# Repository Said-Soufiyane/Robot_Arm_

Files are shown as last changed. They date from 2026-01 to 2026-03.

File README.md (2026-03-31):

# Robot Arm (ESP32) — 6-Axis Desktop Arm (In Progress)

<p align="center">
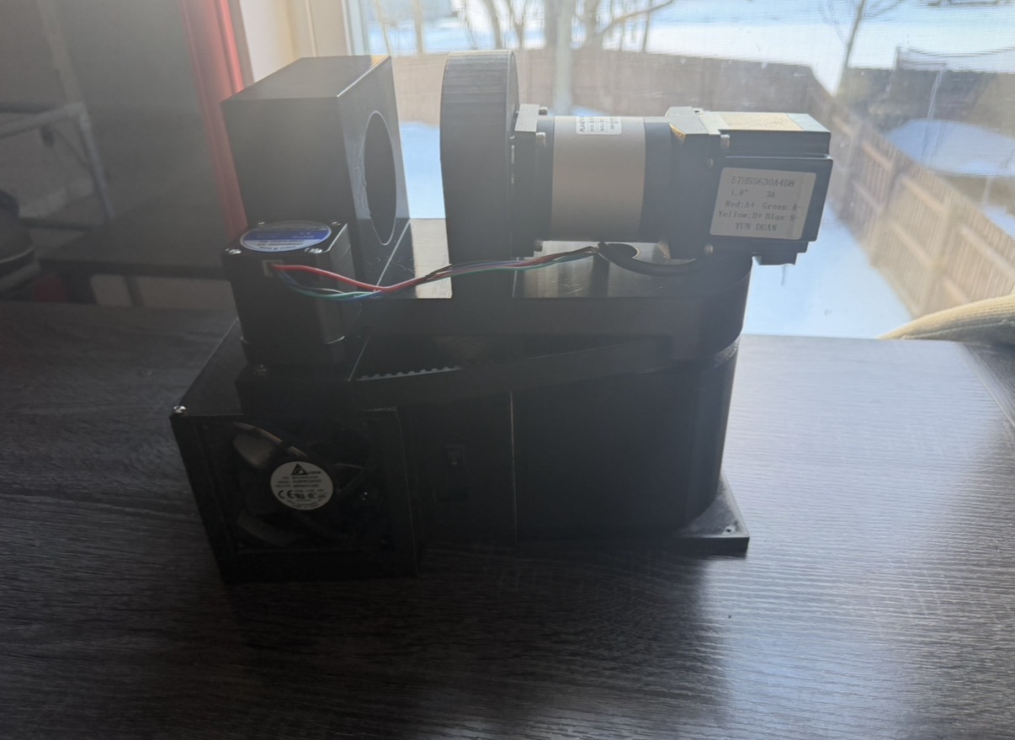
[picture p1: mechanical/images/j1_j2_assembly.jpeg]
Robot Arm cover
  
  <br/><br/>
  PCB test result
  <br/>
  <em>J1/J2 assembly and PCB test result</em>
</p>

A table-mountable 6-axis desktop robot arm project focused on being **publishable, reproducible, and upgradeable**.  
Target is a **real 2.0 kg payload** using **COTS metal planetary gearboxes** on the high-torque joints, with careful bearing design so gearboxes are not used as structural supports.

---

## Status
- Parts: most items arrived; **waiting on gearboxes + NEMA23-related hardware**
- Current work: stepper driver bring-up, bench testing, and PCB validation
- Controller: single-axis tests done earlier; multi-axis control target is **ESP32**

See: `LOGS/robot_arm_engineering_log.txt`

---

## Goals (v0.2)
- **Axes:** 6 (J1–J6)
- **Payload:** 2.0 kg at tool flange (static target, arm extended)
- **Reach:** TBD (goal ~330 mm; acceptable 300–350 mm)
- **Motor rail:** 24V recommended
- **Repeatability:** 0.5–1.0 mm (realistic for stepper + gearbox)
- **Joint speed:** ~30–60°/s on large joints

---

## Architecture Overview

### Drivetrain plan
- J2 (shoulder) + J3 (elbow): COTS metal planetary gearboxes (primary torque joints)
- J1 (base): planetary or belt reduction (TBD)
- J4–J6 (wrist): smaller planetary gearboxes or belt reductions (TBD)

**Mechanical rule (non-negotiable):** Gearboxes are not structural bearings.  
Each joint uses a bearing stack so loads go through bearings, not gearbox shafts.

### Electronics plan
- Controller: **ESP32** for multi-axis control
- Drivers: current-limited stepper drivers such as **TMC2209** and **TB6600-class**
- Control: STEP/DIR per axis, with shared enable optional
- Optional: UART for TMC2209 current tuning and diagnostics

### Power plan
- 24V motor rail for steppers
- Buck converters for 12V fan power and 5V servo power
- Single common ground reference

---

## Repository Layout
- `docs/` — design notes, roadmap, and specs
- `electronics/`
  - `firmware/` — test and controller firmware
  - `pcb/`
    - `source/` — KiCad source files
    - `gerbers/` — fabrication outputs
    - `archive/` — backups and older exports
  - `schematics/images/` — wiring and schematic references
  - `images/` — PCB photos and test result images
- `LOGS/` — engineering log and progress notes
- `mechanical/`
  - `bom/` — bill of materials
  - `exports/stl/` — printable/exported mechanical files
  - `images/` — assembly and mechanical progress images
- `media/`
  - `photos/` — general build photos
  - `Videos/` — short test clips
- `tools/`
  - `calculations/` — supporting calculations
  - `repo_maintenance/` — repo utility scripts

---

## Bring-Up Notes
**Hard rules from bench testing:**
1. Use **current-limited stepper drivers** for 12–24V operation.
2. Add **VM decoupling** near each driver.
3. Keep drivers **disabled by default** during boot and upload.
4. Turn **VM off during MCU upload/reset**.
5. Never hot-plug motor leads.

---

## Media
Build photos, PCB images, and test clips are stored throughout `mechanical/images/`, `electronics/images/`, and `media/`.

---

## Roadmap
- Finish single-axis validation: current setpoint, thermal behavior, and holding torque testing
- Move fully to ESP32 and validate 2–3 axes together
- Assemble one full joint stack and measure backlash and stiffness
- Scale to 6 axes, add homing, and test repeatability
- Publish assembly, wiring, PCB, and firmware documentation

---

## License
TBD

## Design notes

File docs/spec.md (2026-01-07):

# Robot Arm Spec (v0.2)

## Purpose
A table-mountable 6-axis desktop robot arm designed to be publishable, reproducible, and upgradeable.
Primary goal is a **real** 2.0 kg payload capability using **COTS metal planetary gearboxes** on the high-torque joints.

## Target Performance
- Axes: 6 (J1–J6)
- Payload: **2.0 kg at tool flange** (static target, arm extended)
- Reach: **TBD** (recommended: 330 mm; acceptable: 300–350 mm)
- Motor rail: **24 V** system recommended
- Repeatability target: **0.5–1.0 mm** (realistic for stepper + gearbox)
- Typical joint speed: 30–60°/s on large joints (not chasing insane speed)

## Drivetrain Strategy
- J2 (shoulder) + J3 (elbow): **COTS metal planetary gearboxes** (primary torque joints)
- J1 (base yaw): planetary or belt reduction (TBD)
- J4–J6 (wrist): smaller planetary gearboxes or belt reductions (TBD)

### Key Mechanical Rule (non-negotiable)
**Gearboxes should not be used as structural bearings.**
Each joint must have its own bearing stack so arm loads go through bearings, not the gearbox output shaft.

## Electronics / Control (current plan)
- Controller: **ESP32** for multi-axis control (ESP8266 used only for single-axis bench bring-up)
- Motor drivers: **current-limited stepper drivers only** for 12–24V operation (TMC2209/TB6600-class)
- Control interface: STEP/DIR per axis, shared EN optional
- Driver configuration: UART optional (used for current setting + tuning where supported)

### Power / Protection (required for 24V)
- VM decoupling: electrolytic capacitor at each driver across VM–GND (50V rated recommended)
- EN default-disable: pull resistor so drivers stay disabled during boot/upload
- Bring-up rule: **VM OFF during MCU upload/reset**, no hot-plug motor wiring

## Materials / Construction
- Printed parts: PC (primary), with heat-set inserts where needed
- Structural links: printed shells OR aluminum tube links (TBD)
- Pins/shafts: metal (e.g., hardened dowels / steel shafts)
- Bearings: real bearings for every joint, sized based on loads

## Safety / Bring-up
- Emergency stop required during testing
- Mechanical hard-stops where practical
- Cable management to avoid snags and pinch points

## Validation / Tests (minimum)
- Single-axis: coil pairing, current set verification, holding torque “breakaway” test, thermal check
- Multi-axis: simultaneous motion test, no missed steps at target speed/accel, repeatability check
- Mechanical: backlash measurement per joint, stiffness check under load

## Deliverables to Publish
- STEP assembly exports
- STLs for printed parts
- BOM (CSV)
- Assembly + calibration docs
- Firmware + wiring notes
- Media: build photos + short test videos

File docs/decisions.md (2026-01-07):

# Decisions (ADRs)
- ADR: Use current-limited stepper drivers for 12–24V operation (TMC2209/TB6600-class).  
  Reason: DC H-bridges (TB6612/L293/DRV8871) don’t current-limit steppers → high failure risk at 24V.
- ADR: VM OFF during MCU upload/reset; driver disabled by default.  
  Implementation: EN pull-up (10k to 3.3V), plus VM decoupling cap at driver.
- ADR: Single-axis bench bring-up on spare ESP8266; multi-axis control will be ESP32.  
  Reason: ESP8266 GPIO/timing limits for 6 drivers + servo + fan + sensors.
- ADR: Torque-focused settings for testing: SpreadCycle + full-step when validating max torque; microstepping reserved for smooth motion later.
- ADR: Add VM decoupling per driver (electrolytic near MOT VCC/GND).  
  Reason: reduces spikes/dips and improves stability at 24V.

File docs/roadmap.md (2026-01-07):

## Roadmap (next steps)
- Bring-up Phase
  - Verify each motor wiring (coil pairs) + one driver at a time.
  - Validate UART comms (IFCNT changes), then lock current settings per motor.
  - Do a holding torque “breakaway” test and record results.
  - Do a moving torque test with acceleration (no instant speed jumps).
- Multi-axis Phase
  - Move to ESP32 controller.
  - Decide: shared UART bus vs per-driver UART (likely shared).
  - Build a harness: proper connectors, strain relief, common ground, fusing.
  - Implement homing strategy (limit switches or hardstops + repeatability tests).
- Mechanical Phase
  - Finish gearbox stackups once gearboxes arrive.
  - Finalize shaft/rod lengths from real parts + CAD, then cut/deburr.
  - Assemble one joint fully and test backlash, stiffness, and thermal behavior.
- Software Phase
  - Motion planner basics: acceleration ramps, velocity limits, soft limits.
  - Kinematics later (after mechanics stable): FK/IK for 6-axis.
- Documentation Phase (continuous)
  - Keep LOG.md updated with tests, failures, fixes.
  - Add photos/videos to media/ and link from log.
  - Write “Lessons Learned” and “Design Rationale” for final report.

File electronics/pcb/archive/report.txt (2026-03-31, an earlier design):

Info: Output directory 'I:\Projects\Robot_Arm_\electronics\New folder\kicad roboarm\drill files and gerber' created.
Plotted to 'I:\Projects\Robot_Arm_\electronics\New folder\kicad roboarm\drill files and gerber\kicad roboarm-F_Cu.gbr'.
Plotted to 'I:\Projects\Robot_Arm_\electronics\New folder\kicad roboarm\drill files and gerber\kicad roboarm-B_Cu.gbr'.
Plotted to 'I:\Projects\Robot_Arm_\electronics\New folder\kicad roboarm\drill files and gerber\kicad roboarm-F_Silkscreen.gbr'.
Plotted to 'I:\Projects\Robot_Arm_\electronics\New folder\kicad roboarm\drill files and gerber\kicad roboarm-B_Silkscreen.gbr'.
Plotted to 'I:\Projects\Robot_Arm_\electronics\New folder\kicad roboarm\drill files and gerber\kicad roboarm-F_Mask.gbr'.
Plotted to 'I:\Projects\Robot_Arm_\electronics\New folder\kicad roboarm\drill files and gerber\kicad roboarm-B_Mask.gbr'.
Plotted to 'I:\Projects\Robot_Arm_\electronics\New folder\kicad roboarm\drill files and gerber\kicad roboarm-Edge_Cuts.gbr'.
Created Gerber job file 'I:\Projects\Robot_Arm_\electronics\New folder\kicad roboarm\drill files and gerber\kicad roboarm-job.gbrjob'.
Info: Done.
Info: Done.

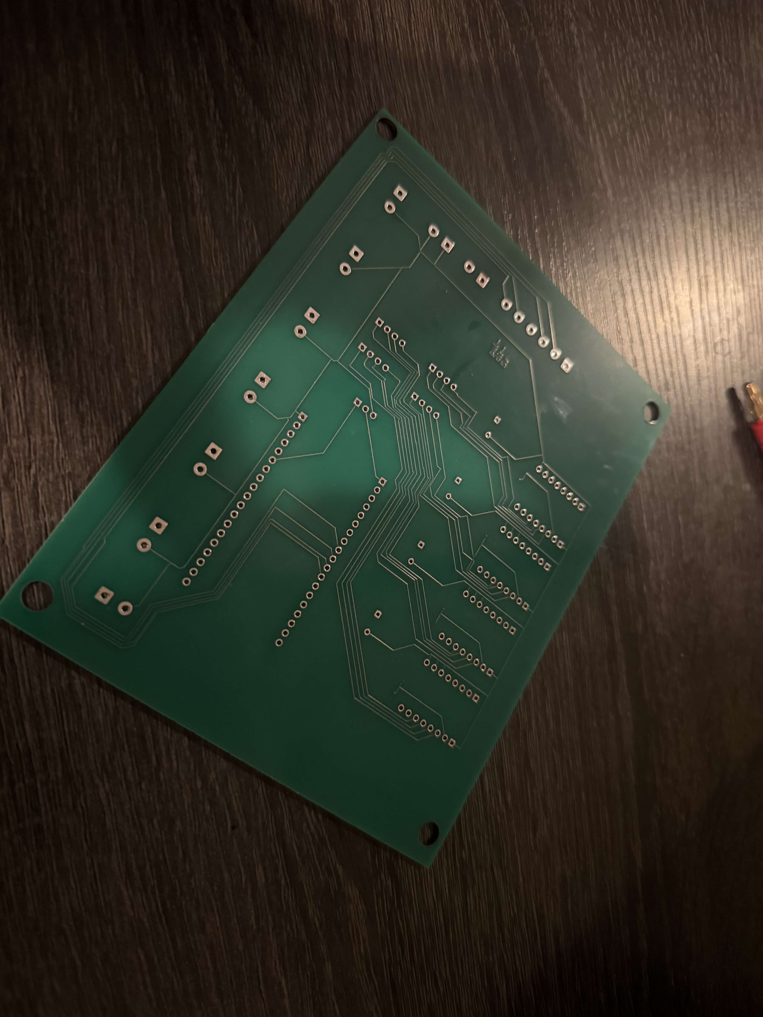
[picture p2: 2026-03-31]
electronics/images/pcb_back.jpeg

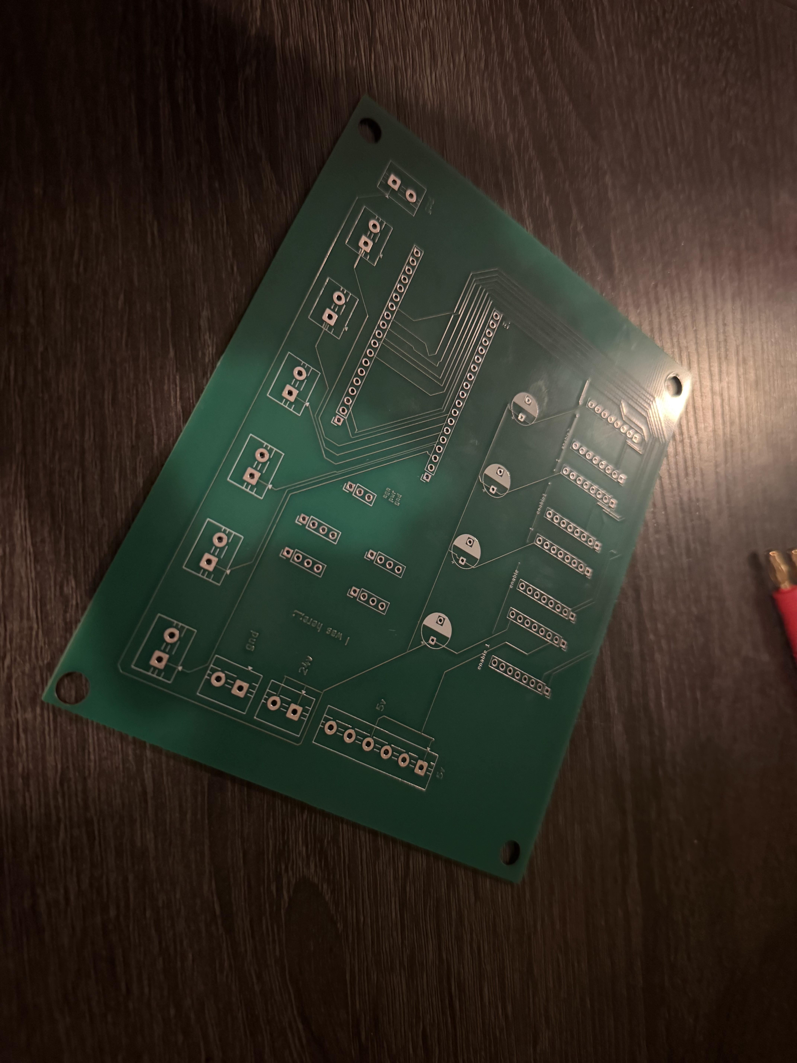
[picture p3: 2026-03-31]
electronics/images/pcb_front.jpeg

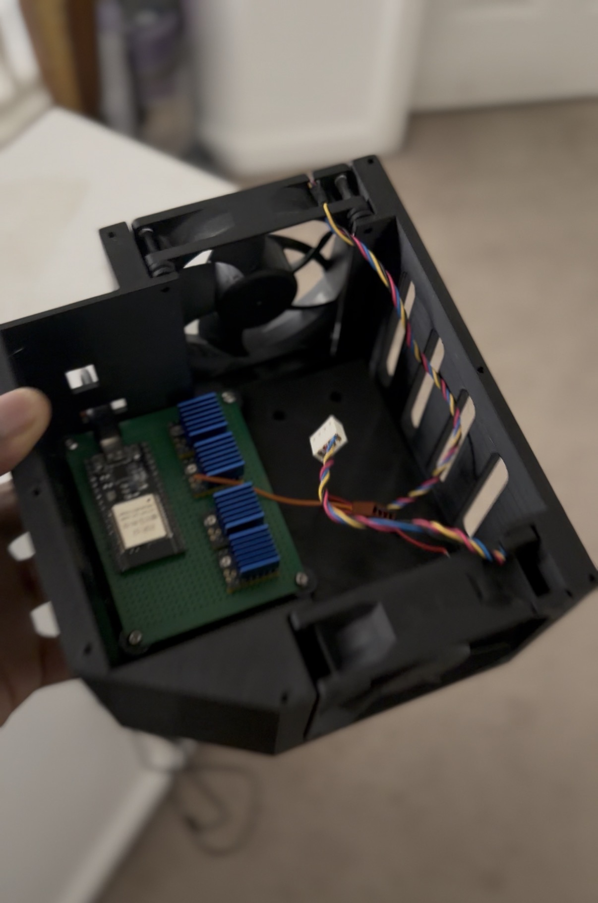
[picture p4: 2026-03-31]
mechanical/images/driver_box_v1.jpeg

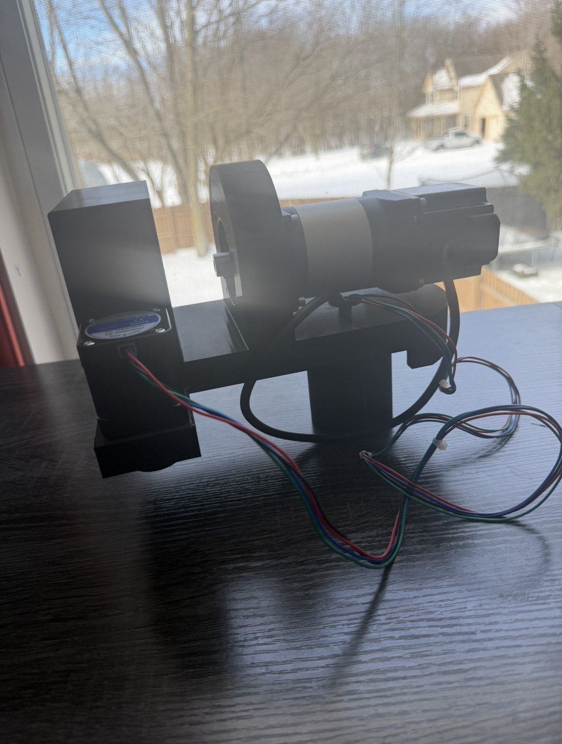
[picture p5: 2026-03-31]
mechanical/images/j1_concept_v1.jpeg

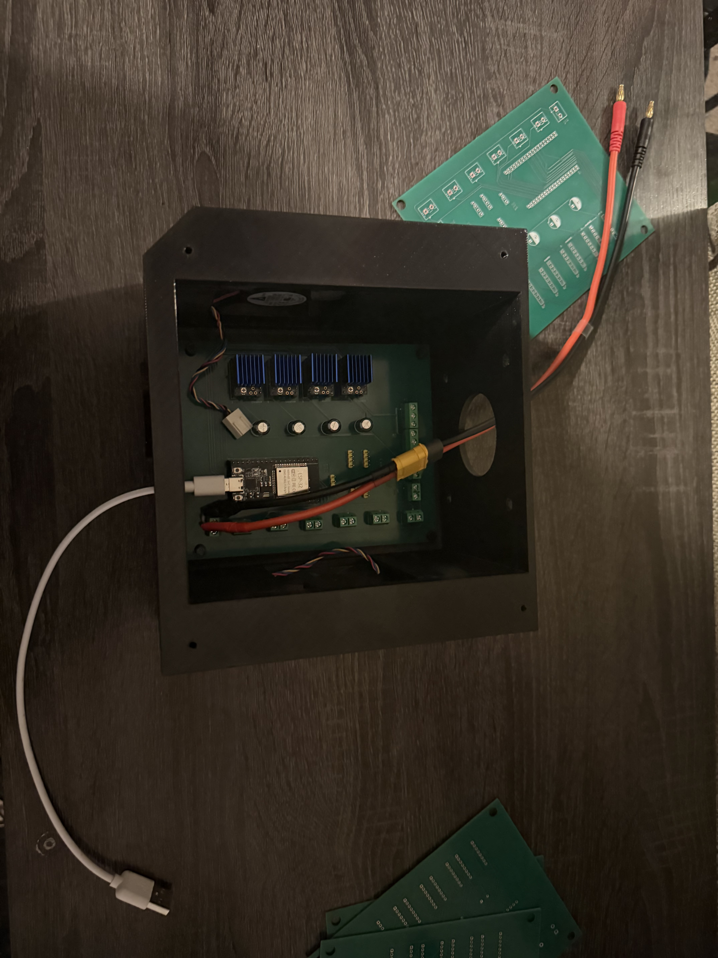
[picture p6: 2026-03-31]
mechanical/images/driver_box_v2.jpeg

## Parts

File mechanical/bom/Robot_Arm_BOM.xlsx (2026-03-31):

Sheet: Summary
Robot Arm Project – Cost Summary
Goal | Affordable bench robot arm, ≥1 kg payload class, total <$350
Paid so far (known totals) | $253.55
Estimated remaining (build-blocking) | $0.00
Estimated optional upgrades | $114.00
Projected total (paid + needed) | $253.55
Projected total (paid + needed + future) | $367.55
Notes | Some Amazon order totals include multiple items (e.g., $19.77 includes both inserts + M3 screw kit). If you want per-item exact costs, paste the invoice line-item prices and I can update. This is a living BOM and will be subject to changes in the forseeable future.

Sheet: Purchased & Owned
Robot Arm BOM – Purchased & Owned
Category | Subsystem | Part | Key specs | Qty | Unit price (item) | Item subtotal | Paid total (if known) | Vendor | Status | Order/ID | Link | Notes
Fasteners | Assembly | Heat-set inserts kit (Quevaeco, 320 pcs) | M3/M4 brass inserts, 10 sizes | 1 | $9.49 | $9.49 | $9.49 | Amazon | Ordered | 111-4629229-2145044 | Heat inserts kit | Paid as part of Amazon order total $19.77 (with M3 screw kit).
Fasteners | Assembly | M3 screw assortment kit (VGBUY, 600 pcs) | M3 socket head + nuts + washers, 6–30mm | 1 | $8.99 | $8.99 | $8.99 | Amazon | Ordered | 111-4629229-2145044 | m3 screw kit | Paid as part of Amazon order total $19.77 (with inserts kit).
Fasteners | Assembly | M4 screw/nut/washer kit (Fgruh, 490 pcs) | M4 socket head + nuts + washers, 6–30mm | 1 | $10.69 | $10.69 | $10.69 | Amazon | Ordered | 111-3472011-3016224 | m4 screw kit (https://www.amazon.com/dp/B0FG2D92BV?ref=ppx_yo2ov_dt_b_fed_asin_title&th=1) | Order total $10.69.
Mechanical | J3 support | 608-2RS bearings (SHKI, 20 pcs) | 8×22×7mm, double rubber seal | 20 | $0.35 | $6.99 | $6.99 | Amazon | Ordered | 113-8232466-0171457 | 608 2rs bearings | Use 2 for J3 axle; extras for idlers/other joints.
Mechanical | J3 support | 8mm hardened shaft rods (2-pack) | 8mm × 400mm, h8 tolerance | 2 | $7.00 | $13.99 | $13.99 | Amazon | Ordered | 113-8232466-0171457 | Shaft rods | Cut for J3 axle (now) and future axles.
Mechanical | J3 support | 8mm→8mm rigid coupling | L=25mm, D=20mm, aluminum | 1 | $9.49 | $9.49 | $9.49 | Amazon | Ordered | 113-8232466-0171457 | 8mm shaft coupling | Gearbox output to axle (J3).
Mechanical | J3 support | 8mm split-clamp shaft collars (uxcell, 6 pcs) | Two-piece clamp, 8mm bore, 25mm OD | 6 | $1.53 | $9.19 | $9.19 | Amazon | Have | 113-8232466-0171457 | Shaft collar (https://www.amazon.com/dp/B0FGX7KR9T?ref=ppx_yo2ov_dt_b_fed_asin_title) | Use 2 for J3; remaining are spares.
Actuators | J1/J3/J4–J6 | NEMA17 stepper motors (StepperOnline, 5-pack) | 42×42×48mm, 2.0A, ~59Ncm holding | 5 | $11.00 | $55.00 | $55.00 | Amazon | Have | 113-8232466-0171457 | Nema 17 (https://www.amazon.com/dp/B00QEYADRQ) | Use 1 for J1, 1 for J3 input, 3 for J4–J6.
Drivers | Stepper drivers | TMC2209 V2.0 StepStick drivers (Teyleten, 5-pack) | UART-capable, heatsinks included | 5 | $4.40 | $21.99 | $21.99 | Amazon | Have | 113-4114293-2781827 | TMC2209 drivers (https://www.amazon.com/dp/B09BK57KNY) | Paid total shown as $23.53.
Transmission | J3 gearbox | NEMA17 planetary gearbox | 50:1, input 5mm, output 8mm | 1 | $24.25 | $24.25 | $35.43 | AliExpress | Have | 8208237185546697 | Nema17 planetary (https://www.aliexpress.us/item/3256810249188589.html) | Paid total shown as $35.43 (import charges included).
Actuator+Transmission | J2 gearbox+driver | NEMA23 planetary kit (motor + 50:1 gearbox + TB6600) | Motor 1.2N·m, output 14mm keyed | 1 | $67.57 | $67.57 | $72.30 | AliExpress | Have | 8208237185566697 | Nema 23 Kit (https://www.aliexpress.us/item/3256809288060861.html) | Paid total shown as $72.30.
Control | Controller | ESP32 dev board | USB powered, 3.3V logic | 1 | $0.00 | $0.00 | $0.00 | Existing | Have |  |  | Power via bench PSU USB port.
Power | Supply | Bench power supply | 30V 10A + USB 5V port | 1 | $0.00 | $0.00 | $0.00 | Existing | Have |  |  | Run motors ~24V; USB powers ESP32.
Safety | E-stop | Kill switch | Use as VMOT cut if DC-rated | 1 | $0.00 | $0.00 | $0.00 | Existing | Have |  |  | Prefer cutting VMOT to all drivers.
Cooling | Electronics cooling | PC fan | Any spare 12V/24V fan | 1 | $0.00 | $0.00 | $0.00 | Existing | Have |  |  | Blow across TMC2209 heatsinks.
Sensors | Limits | Roller limit switches | Microswitch rollers | 6 | $0.00 | $0.00 | $0.00 | Existing | Have |  |  | Use for homing/limits.
End effector | Gripper | MG995 servo | Metal gear servo | 1 | $0.00 | $0.00 | $0.00 | Existing | Have |  |  | Use for simple claw.
Materials | Printing | Filament | ABS/PETG/PC | 1 | $0.00 | $0.00 | $0.00 | Existing | Have |  |  | PC recommended for hub/clamps; PETG/ABS for covers.
Wiring | Electronics | Hookup wire | 22 AWG (signals + short VMOT runs) | 1 | $0.00 | $0.00 | $0.00 | Existing | Have |  |  | Assumed on-hand per user.
Consumables | Electronics | Heatshrink / electrical tape | Insulation + strain relief | 1 | $0.00 | $0.00 | $0.00 | Existing | Have |  |  | Assumed on-hand per user.
Consumables | Electronics | Zip ties | Wire management | 1 | $0.00 | $0.00 | $0.00 | Existing | Have |  |  | Assumed on-hand per user.
Prototyping | Electronics | Breadboard | Temporary bring-up / testing only | 1 | $0.00 | $0.00 | $0.00 | Existing | Have |  |  | Assumed on-hand per user.
Prototyping | Electronics | Perfboard (small) | For more reliable driver wiring than breadboard | 1 | $0.00 | $0.00 | $0.00 | Existing | Have |  |  | Assumed on-hand per user.
Tools | Electronics | Soldering iron + solder | For headers/wires if needed | 1 | $0.00 | $0.00 | $0.00 | Existing | Have |  |  | Assumed on-hand per user.
 |  |  | TOTAL (Paid totals only) |  |  |  | $253.55

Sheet: Needed to Run
Robot Arm – Parts Needed to Run (Build-Blocking)
Category | Subsystem | Part | Key specs | Qty | Est. unit cost | Vendor | Status | Link | Notes
Mechanicals | Printed parts | Printed structural parts (base + links + motor mounts) | Enough parts to assemble v1 arm + short test links | 1 | $0.00 | 3D Printed | Required |  | Print short test links first; full-length links after joints pass load test.
Mechanicals | J3 hub | J3 bearing block / axle support | 2× 608 pockets (8x22x7) + 8mm shaft capture + collar clearance | 1 | $0.00 | 3D Printed | Required |  | Bearings carry load; gearbox only drives rotation.
Mechanicals | J2 hub | Printed keyed split-clamp hub | 14mm keyed bore + keyway; split clamp; bolt pattern for upper arm link | 1 | $0.00 | 3D Printed | Required |  | Measure key width/height when kit arrives; print in PC if possible.
 |  |  | TOTAL (estimated) |  | $0.00

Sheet: Future Upgrades
Robot Arm – Future Upgrades (Not required for v1 goals)
Category | Subsystem | Part | Key specs | Qty | Est. unit cost | Vendor | Priority | Notes
Safety | E-stop | Dedicated latching mushroom E-stop (DC-rated) | NC contacts, panel mount | 1 | $12.00 | Amazon | Optional | Better than a generic switch if yours isn't DC-rated.
Power | Electronics | 24V→5V buck converter (standalone) | LM2596 or similar | 1 | $6.00 | Amazon | Optional | Not required if ESP32 stays USB-powered.
Mechanicals | J2 stiffness | J2 external support bearings + axle | Bearing-supported shoulder output to reduce gearbox bending load | 1 | $25.00 | Mixed | Optional | Upgrade if you see flex/wobble.
Mechanicals | Cable management | Cable chain + mounts | Keeps wires from snagging | 1 | $15.00 | Amazon | Optional
Sensing | Precision | Encoders (closed-loop upgrade) | For higher precision / anti-skip | 6 | $10.00 | AliExpress | Optional | Not needed for 1kg-class open-loop goals.
End effector | Gripper | Better gripper (servo/stepper) | Higher grip force + better jaws | 1 | $20.00 | Mixed | Optional
Safety | Power protection | Inline fuse + holder | Blade fuse holder + 5–10A fuse | 1 | $8.00 | Amazon | Optional | Good protection against wiring shorts; not required if careful with bench PSU current limit.
Wiring | Power distribution | Terminal blocks / lever nuts | Convenience for VMOT/GND bus (WAGO-style or screw terminals) | 1 | $10.00 | Amazon | Optional | Not required; makes rewiring easier + cleaner.
Wiring | Power distribution | Heavier motor power wire | 18–20 AWG for VMOT/GND bus (recommended for final build) | 1 | $8.00 | Amazon | Optional | You can start with 22 AWG for short runs; upgrade later.
 |  |  | TOTAL (estimated) |  | $114.00

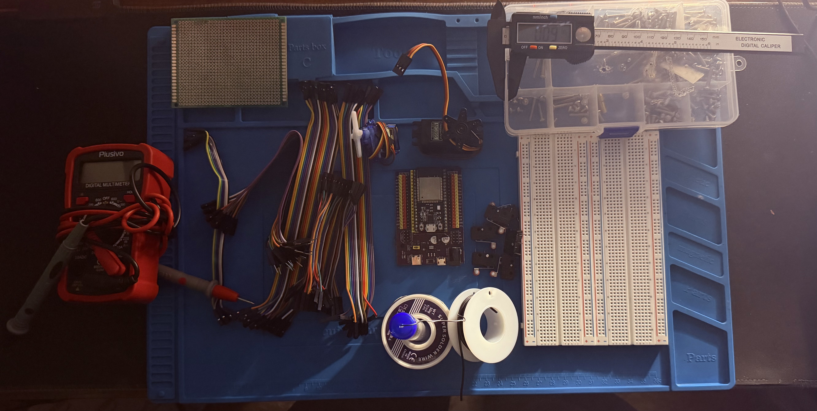
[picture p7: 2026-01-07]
media/photos/Parts1.jpeg

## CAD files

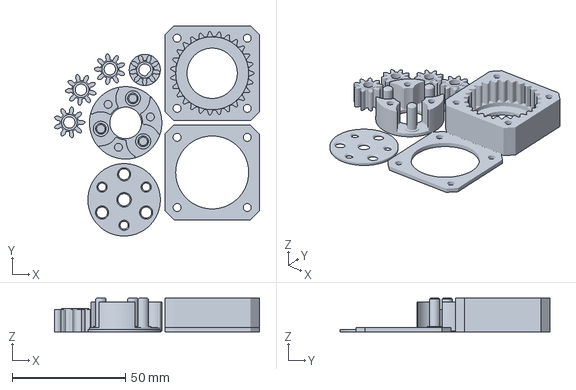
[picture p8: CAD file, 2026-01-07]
mechanical/exports/stl/Planetary gear_4to1_complete.3mf
90.6 x 92.8 x 15.0 mm

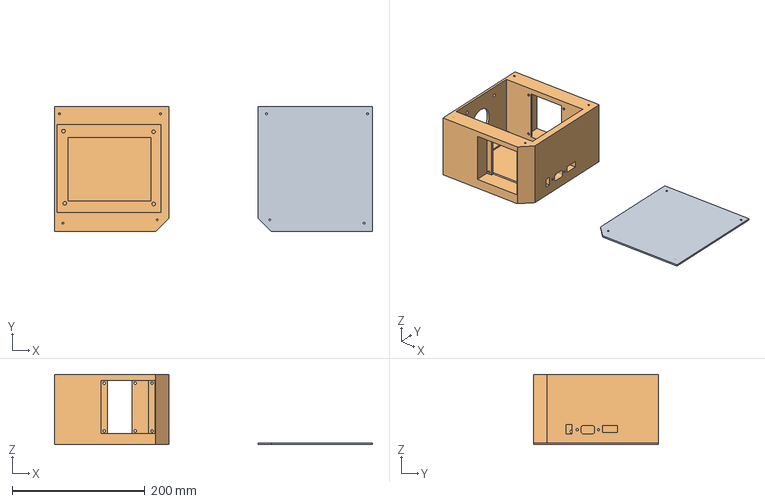
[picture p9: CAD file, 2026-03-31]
mechanical/exports/stl/electronics box.3mf
479.9 x 189.0 x 106.0 mm
lid2.0.stl
driverbox 2.0.stl

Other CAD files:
electronics/pcb/source/roboarm.step

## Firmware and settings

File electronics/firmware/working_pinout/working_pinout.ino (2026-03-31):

/* FULL WORKING PINOUT — ESP32 (38-pin)
Driver plan: TB6600 = J2/J3 (NEMA23). TMC2209 = J1/J4/J5/J6 (NEMA17).
UART is ONLY for J1 (TMC #1).

========================
SHARED ENABLE (TMC only)
========================
TMC_EN_BUS -> GPIO21
- Tie ALL TMC2209 EN pins (J1-1 on each TMC) together to GPIO21
- In code: EN LOW = enabled, EN HIGH = disabled (active LOW)
- TB6600 ENA is separate (don’t tie it into this bus)

========================
TB6600 #1  (J2 / NEMA23)
========================
STEP/PUL- -> GPIO25
DIR/DIR-  -> GPIO26
PUL+ & DIR+ -> ESP32 5V (USB 5V)  [common-anode]
(ENA optional: ENA+ -> 5V, ENA- -> GND)

========================
TB6600 #2  (J3 / NEMA23)
========================
STEP/PUL- -> GPIO27
DIR/DIR-  -> GPIO14
PUL+ & DIR+ -> ESP32 5V (USB 5V)  [common-anode]
(ENA optional: ENA+ -> 5V, ENA- -> GND)

========================
TMC2209 #1 (J1 / NEMA17)  [UART-configured]
========================
STEP -> GPIO23
DIR  -> GPIO22
EN   -> GPIO21  (shared EN bus)

UART (PDN_UART pin on the driver, J1-4 OR J1-5):
  RX -> GPIO4
  TX -> GPIO5   (1k series resistor on TX recommended)

========================
TMC2209 #2 (J4 / NEMA17)
========================
STEP -> GPIO19
DIR  -> GPIO18
EN   -> GPIO21  (shared EN bus)
PDN_UART not connected (optional later)

========================
TMC2209 #3 (J5 / NEMA17)
========================
STEP -> GPIO17
DIR  -> GPIO16
EN   -> GPIO21  (shared EN bus)
PDN_UART not connected (optional later)

========================
TMC2209 #4 (J6 / NEMA17)
========================
STEP -> GPIO33
DIR  -> GPIO32
EN   -> GPIO21  (shared EN bus)
PDN_UART not connected (optional later)

========================
SERVO (gripper)
========================
Signal -> GPIO13
Power  -> external +5V brick (NOT ESP32 5V)
GND    -> external GND tied to ESP32 GND

========================
LIMIT SWITCHES (one per axis)
Wire each switch between GPIO and GND, use INPUT_PULLUP
(Pressed = LOW)
========================
J1 limit -> GPIO34
J2 limit -> GPIO35
J3 limit -> GPIO36
J4 limit -> GPIO39
J5 limit -> GPIO12
J6 limit -> GPIO15*/

#include <Arduino.h>

// No-UART STEP/DIR test for TMC2209
// STEP -> GPIO23, DIR -> GPIO22

const int STEP_PIN = 23;
const int DIR_PIN  = 22;

void setup() {
  pinMode(STEP_PIN, OUTPUT);
  pinMode(DIR_PIN, OUTPUT);
  digitalWrite(STEP_PIN, LOW);
  digitalWrite(DIR_PIN, LOW);
  delay(500);
}

void stepOnce() {
  digitalWrite(STEP_PIN, HIGH);
  delayMicroseconds(5);
  digitalWrite(STEP_PIN, LOW);
}

void runSteps(uint32_t steps, uint16_t stepDelayMs) {
  for (uint32_t i = 0; i < steps; i++) {
    stepOnce();
    delay(stepDelayMs); // super slow on purpose
  }
}

void loop() {
  // Forward crawl
  digitalWrite(DIR_PIN, LOW);
  runSteps(400, 10);   // 100 steps/sec (very slow)
  delay(500);

  // Reverse crawl
  digitalWrite(DIR_PIN, HIGH);
  runSteps(400, 10);
  delay(1200);
}

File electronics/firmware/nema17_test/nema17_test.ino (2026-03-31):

// // //constant stream of step pulses
// #include <TMCStepper.h>

// #define STEP_PIN 14   // GPIO14
// #define DIR_PIN  12   // GPIO12
// #define EN_PIN   13   // GPIO13

// #define SERIAL_PORT Serial
// #define R_SENSE 0.11f   // Correct for Teyleten Robot TMC2209

// TMC2209Stepper driver(&SERIAL_PORT, R_SENSE, 0b00);

// void setup() {
//   SERIAL_PORT.begin(115200);

//   pinMode(STEP_PIN, OUTPUT);
//   pinMode(DIR_PIN, OUTPUT);
//   pinMode(EN_PIN, OUTPUT);

//   digitalWrite(EN_PIN, LOW); // Enable driver

//   driver.begin();
//   driver.rms_current(1200);      // SET CURRENT HERE (1.2A RMS)
//   driver.microsteps(16);
//   driver.en_spreadCycle(false);  // StealthChop ON
// }

// void loop() {
//   digitalWrite(STEP_PIN, HIGH);
//   delayMicroseconds(800);
//   digitalWrite(STEP_PIN, LOW);
//   delayMicroseconds(800);
// }

// Code for HOLDING torque test
// #include <TMCStepper.h>

// #define STEP_PIN 14   // GPIO14
// #define DIR_PIN  12   // GPIO12
// #define EN_PIN   13   // GPIO13

// #define SERIAL_PORT Serial
// #define R_SENSE 0.11f

// TMC2209Stepper driver(&SERIAL_PORT, R_SENSE, 0b00);

// void setup() {
//   SERIAL_PORT.begin(115200);

//   pinMode(STEP_PIN, OUTPUT);
//   pinMode(DIR_PIN, OUTPUT);
//   pinMode(EN_PIN, OUTPUT);

//   digitalWrite(DIR_PIN, LOW);
//   digitalWrite(EN_PIN, LOW); // enable 

//   driver.begin();
//   driver.pdn_disable(true);
//   driver.I_scale_analog(false);

//   driver.toff(4);                // 
//   driver.en_spreadCycle(true);   // max torque mode 
//   driver.microsteps(1);          // full step for max holding torque
//   driver.rms_current(1200);      // change this for your test points
// }

// void loop() {

// }
/*
  ESP8266 + TMC2209 (StepStick) — 24V, 2.0A RMS torque test
    STEP = GPIO14
    DIR  = GPIO12
    EN   = GPIO13 (active LOW on most boards)

  UART pins for PDN_UART (recommended and boot-safe):
    RX = GPIO4
    TX = GPIO5  (put 1k resistor in series from TX -> PDN_UART)

  Notes:
  - 24V is your motor supply (VM).
  - Current (2.0A RMS) .
  - SpreadCycle + full-step = max torque/holding.
*/

#include <Arduino.h>
#include <SoftwareSerial.h>
#include <TMCStepper.h>


#define STEP_PIN 23   // GPIO14
#define DIR_PIN  22   // GPIO12
#define EN_PIN   13   // GPIO13

// --- UART (PDN_UART) pins ---
#define UART_RX  4    // GPIO4  (D2)
#define UART_TX  5    // GPIO5  (D1)  -> add 1k series resistor to PDN_UART

// --- Driver config ---
#define R_SENSE 0.11f
#define DRIVER_ADDR 0b00

SoftwareSerial TMCSerial(UART_RX, UART_TX);  // RX, TX
TMC2209Stepper driver(&TMCSerial, R_SENSE, DRIVER_ADDR);

// --- Torque settings ---
const int RMS_mA = 2000;      // 2.0A RMS (aggressive; requires heatsink+fan)
const bool SPIN_MODE = true;  // true = rotate slowly, false = hold only
int stepDelayUs = 2000;       // increase (2000-4000) if it stalls under load

static inline void stepPulse() {
  digitalWrite(STEP_PIN, HIGH);
  delayMicroseconds(stepDelayUs);
  digitalWrite(STEP_PIN, LOW);
  delayMicroseconds(stepDelayUs);
}

void setup() {
  Serial.begin(115200);
  delay(200);

  pinMode(STEP_PIN, OUTPUT);
  pinMode(DIR_PIN, OUTPUT);
  pinMode(EN_PIN, OUTPUT);

  // Start disabled (safer during boot)
  digitalWrite(EN_PIN, HIGH);     // disable (active LOW)
  digitalWrite(DIR_PIN, LOW);
  delay(50);

  // Start UART to driver
  TMCSerial.begin(115200);

  // Init + configure driver
  driver.begin();
  driver.pdn_disable(true);       // PDN_UART pin used for UART
  driver.I_scale_analog(false);   // use UART current control

  driver.toff(4);                 // REQUIRED: enable power stage
  driver.blank_time(24);

  driver.en_spreadCycle(true);    // torque/accuracy mode
  driver.microsteps(1);           // full-step for max torque
  driver.rms_current(RMS_mA);     // ⭐ max torque current
  driver.pwm_autoscale(true);

  // Enable after configuration
  digitalWrite(EN_PIN, LOW);      // enable (active LOW)

  Serial.println("TMC2209 configured: 2.0A RMS, SpreadCycle, full-step");
}

void loop() {
  if (!SPIN_MODE) {
    // HOLD torque test
    delay(1000);
    return;
  }

  // MOVING torque test (slow rotation)
  stepPulse();
}

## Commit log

2026-01-07 Update log, specs, and wiring notes; add media structure
    [Planetary gear_4to1_complete.3mf, Robot_Arm_BOM.xlsx]
2026-01-07 Create README.md for robot arm project
    Add initial README for 6-axis desktop robot arm project
2026-01-07 Enhance README with images and project details
    Added additional images and description for the robot arm project.
2026-01-07 Adjust cover image size in README
    Updated image size for the Robot Arm cover.
2026-02-04 Update engineering log with recent progress and plans
    Added detailed logs of engineering progress, including completed tasks, issues encountered, and next steps for the robot arm project.
2026-03-31 Change image source in README.md
    Updated image source path for the Robot Arm cover.
2026-03-31 Clean up Robot Arm repo structure and organize project files
    [Robot_Arm_BOM.xlsx, electronics box.3mf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]
